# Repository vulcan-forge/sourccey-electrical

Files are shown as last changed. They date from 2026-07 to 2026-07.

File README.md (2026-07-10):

# Sourccey Electrical

Open-source hardware design files for the Sourccey electrical system.

This repository is intended to contain the complete KiCad design source,
component data, and documentation needed to inspect, modify, manufacture,
and assemble the hardware.

## Status

This repository contains the Sourccey v1.3.8 electrical design release.
Always review the release notes and complete your own manufacturing and safety
validation before building hardware.

## Repository layout

The repository is organized by editable design sources, manufacturing outputs,
and supporting documentation:

```text
.
├── pcb/
│   ├── <board-name>.kicad_pro
│   ├── <board-name>.kicad_sch
│   ├── <board-name>.kicad_pcb
│   ├── symbols/             # Project-specific KiCad symbols
│   └── footprints/          # Project-specific KiCad footprints
├── bom/
│   ├── bom.csv              # Human/reviewable bill of materials
│   └── pos.csv              # Pick-and-place / centroid data
├── fab/                     # Released Gerbers and drill files, if tracked
├── docs/                    # Design notes, assembly, and test instructions
└── README.md
```

The generic layout above describes the intended convention for additional
boards. The current checked-in release is organized as follows:

```text
.
|-- pcb/sourccey-v1.3.8/
|   |-- *.kicad_pro       # KiCad project
|   |-- *.kicad_sch       # Main and hierarchical schematics
|   |-- *.kicad_pcb       # PCB layout
|   |-- symbols/           # Project-specific KiCad symbols
|   |-- footprints/        # Project-specific KiCad footprints
|   `-- models/            # Optional 3D model references
|-- manufacturing/sourccey-v1.3.8/
|   |-- gerbers/           # Gerbers, drill files, and Gerber archive
|   |-- bom/               # Bill of materials exports
|   `-- cpl/               # Pick-and-place / component placement exports
|-- docs/                  # Design notes, assembly, and test instructions
`-- README.md
```

Each board should keep its `.kicad_pro`,
`.kicad_sch`, and `.kicad_pcb` files together. Do not commit KiCad lock files,
personal project settings, or backup files.

## Opening the design

The current design is Sourccey v1.3.8 and was saved with KiCad 9.0.

1. Install [KiCad 9](https://www.kicad.org/download/), including the standard
   symbol, footprint, and 3D-model libraries.
2. Clone this repository.
3. Open
   `pcb/sourccey-v1.3.8/sourccey_pcb.kicad_pro`.
4. Review the schematic before opening or editing the PCB.
5. Update the project libraries only with care: project-local symbols and
   footprints should be stored in this repository so the design remains
   reproducible.

The project includes its hierarchical `Power Electronics.kicad_sch` sheet and
the custom DRV8874 symbol and footprint. See the README under the version's
`models/` directory for two optional STEP models that are not yet included.

## BOM and POS data

The `manufacturing/sourccey-v1.3.8/` directory contains the files needed to
order and assemble the board:

- Gerbers for copper, solder mask, solder paste, silkscreen, and the board
  outline, plus the Gerber job file and packaged archive.
- PTH and NPTH drill files for plated and non-plated holes.
- A KiCad BOM export and a vendor-formatted BOM for purchasing.
- KiCad and vendor-formatted CPL (component placement / pick-and-place) data.

These are manufacturing outputs, not the editable source of truth. Regenerate
them from the released KiCad project whenever the design changes.

The BOM should identify at least:

- Reference designators
- Quantity
- Value and footprint
- Manufacturer and manufacturer part number, when known
- Distributor part number, when known
- Designator exclusions or DNP status

The POS file should identify each populated reference, X/Y position, rotation,
side, and the coordinate origin used for the export. BOM and POS exports are
manufacturing inputs: regenerate them from the released KiCad sources and
record the KiCad version and export settings in the release notes.

## Manufacturing components

Manufacturing outputs are generated from the released PCB source. A release
should include, or link to, the corresponding Gerber, drill, drawing, BOM, and
POS package. Keep generated outputs in `fab/` or a release artifact rather than
mixing them with editable KiCad source files.

The checked-in v1.3.8 outputs are under
`manufacturing/sourccey-v1.3.8/`, including original and vendor-formatted BOM
and CPL files, Gerbers, drill files, and the Gerber archive.

The PCB uses 2 oz copper on the copper layers. Confirm the fabricator's stackup
and copper-weight capabilities before ordering.

Before manufacturing, check at minimum:

- Schematic and PCB annotations are synchronized.
- Electrical rules and design rules pass.
- Board outline, mounting holes, clearances, and layer stack are correct.
- Footprints and 3D/component orientations are correct.
- BOM substitutions, DNP parts, polarity, and assembly side are reviewed.
- Gerbers and drill files are inspected in a separate viewer.

## Documentation

See the [Vulcan Robotics documentation](https://vulcanrobotics.ai/docs) for the
broader Sourccey project. This repository is the electrical reference for
wiring and board-level build details. The documentation site also links to the
related hardware, software, and LeRobot-compatible repositories. Software setup
and hardware-kit assembly instructions are currently listed there as coming
soon.

## Release notes

See [RELEASE_NOTES.md](RELEASE_NOTES.md) for the v1.3.8 release summary,
manufacturing package details, and validation record.

## Contributing

Please open an issue before making a substantial design change. Pull requests
should explain the motivation, identify affected boards, and include updated
schematic/PCB files and regenerated BOM/POS or manufacturing outputs when
applicable. Include screenshots or test results for changes that affect layout,
assembly, or electrical behavior.

## Licensing

Unless stated otherwise in a subdirectory, this project is released under the
[CERN Open Hardware Licence Version 2 - Strongly Reciprocal
(CERN-OHL-S-2.0)](https://gitlab.com/ohwr/project/cernohl/-/wikis/uploads/819d71bea3458f71fba6cf4fb0f2de6b/cern_ohl_s_v2.txt).
This license permits personal, educational, commercial, and manufacturing use.
If you distribute a modified design or a product based on it, you must preserve
the notices, make the corresponding source available, and license the modified
covered source under CERN-OHL-S-2.0. Private modifications do not need to be
published unless they are distributed.

Add the full license text as `LICENSE` before publishing the repository.

Third-party symbols, footprints, models, and datasheets may have separate
licenses. Preserve their notices and verify redistribution rights before
committing them.

## Disclaimer

This hardware is provided without warranty. You are responsible for reviewing
the design, complying with applicable laws and safety requirements, and
validating any manufactured or modified hardware before use.

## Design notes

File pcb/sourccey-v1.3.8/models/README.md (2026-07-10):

# Project-local 3D models

The PCB references the following project-local STEP models:

- `DRV8874PWPR.stp`
- `XT30AW-M.stp`

These files were referenced from another developer's local KiCad installation
but were not available in the source tree when this release was assembled.
Place redistributable copies at the paths above to restore those models in
KiCad's 3D viewer. Their absence does not prevent the schematic or PCB editor
from opening.

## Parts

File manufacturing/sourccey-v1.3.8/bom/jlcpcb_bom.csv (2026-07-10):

Comment | Designator | Footprint | JLCPCB Part #
DRV8874PWPR | U2,U3,U1,U5,U4 | PWP0016J_L | C1855818
TPS7A1633DGNR | U9 | MSOP-8-1EP_3x3mm_P0.65mm_EP1.5x1.8mm | C181239
R 249k Ohm | R42 | R_0805_2012Metric | C218450
0.1uF | C32,C5,C43,C40,C56,C57,C19,C23,C54,C55,C10,C7,C20,C3,C37,C6,C22,C52,C17,C18,C35,C8,C46,C9,C30,C21,C15,C49,C16 | C_0603_1608Metric | C14663
22nF | C27,C28,C25,C24,C26 | C_0402_1005Metric | C1532
R 100k Ohm | R3,R1,R8,R6,R45,R31,R9,R40,R7,R2,R4,R5,R10 | R_0805_2012Metric | C25611
D_Schottky | D2 | D_SMB | C22452
R 24k Ohm | R39 | R_0805_2012Metric | C17575
R 100 Ohm | R47 | R_0805_2012Metric | C22775
Conn_01x02_Pin | J9,J13,J18,J16,J5,J6,J4,J14,J11,J8,J2,J17,J15,J12,J3 | AMASS_XT30UPB-M_1x02_P5.0mm_Vertical | C428721
R 10k Ohm | R48,R37,R23,R11,R15,R26,R18,R49,R22,R19,R35,R50,R34,R27,R30,R14,R46 | R_0805_2012Metric | C17414
R 20k Ohm | R13,R25,R21,R17,R29 | R_0805_2012Metric | C4328
22uF | C38,C48,C34,C51 | C_1206_3216Metric | C12891
100uF | C4,C13,C14,C12,C11,C1 | CP_Elec_6.3x7.7 | C3338
R 680 Ohm | R12,R20,R16,R24,R28 | R_0805_2012Metric | C17798
R 1k Ohm | R33 | R_0805_2012Metric | C702831
10uF | C29,C45,C53 | C_0805_2012Metric | C15850
Conn_01x04_Pin | J19 | JST_SH_BM04B-SRSS-TB_1x04-1MP_P1.00mm_Vertical | C160390
Conn_02x20_Odd_Even | J1 | PinHeader_2x20_P2.54mm_Vertical | C5224014
Conn_01x03 | J7 | JST_XH_B3B-XH-A_1x03_P2.50mm_Vertical | C146133
R 12.5m Ohm | R36 | R_2512_6332Metric | C5375465
TestPoint | TP2,TP3,TP6,TP1,TP4,TP5 | TestPoint_Pad_2.0x2.0mm
IRLZ44N | Q3 | TO-220-3_Vertical | C22367197
4700uF | C33,C36,C47,C50 | CP_Radial_D13.0mm_P5.00mm | C29884
10 nF | C41 | C_0603_1608Metric | C57112
R 68 Ohm | R41,R44 | R_0603_1608Metric | C23228
LTC4365DDB | U8 | DFN-8-1EP_2x3mm_P0.5mm_EP0.61x2.2mm | C117337
SW_SPST | FuelGaugeSwitch1,LightSwitch1 | SW_SPDT_PCM12 | C431540
10k NTC | TH1 | JST_XH_B2B-XH-A_1x02_P2.50mm_Vertical | C158012
NMOS | Q1,Q2 | TO-220-3_Vertical | C841350
1uF | C42,C31,C2,C39 | C_0805_2012Metric | C15849
MCP3008 | U7 | SOIC-16_3.9x9.9mm_P1.27mm | C2651321
TCA9517D | U10 | SOIC-8_3.9x4.9mm_P1.27mm | C182421
BQ34Z100PWR-R2 | U6 | TSSOP-14_4.4x5mm_P0.65mm | C7220642
1000uF | C44 | CP_Radial_D10.0mm_P5.00mm | C439782
16V_TVS | D1 | D_SMB | C113990
Conn_01x04_Pin | J20 | Molex_KK-254_AE-6410-04A_1x04_P2.54mm_Vertical | C504991
R 16.5k Ohm | R43 | R_0805_2012Metric | C2930171
R 510k Ohm | R38 | R_0805_2012Metric | C17733
Conn_01x01_Pin | J10 | PinHeader_1x01_P2.54mm_Vertical | C492400

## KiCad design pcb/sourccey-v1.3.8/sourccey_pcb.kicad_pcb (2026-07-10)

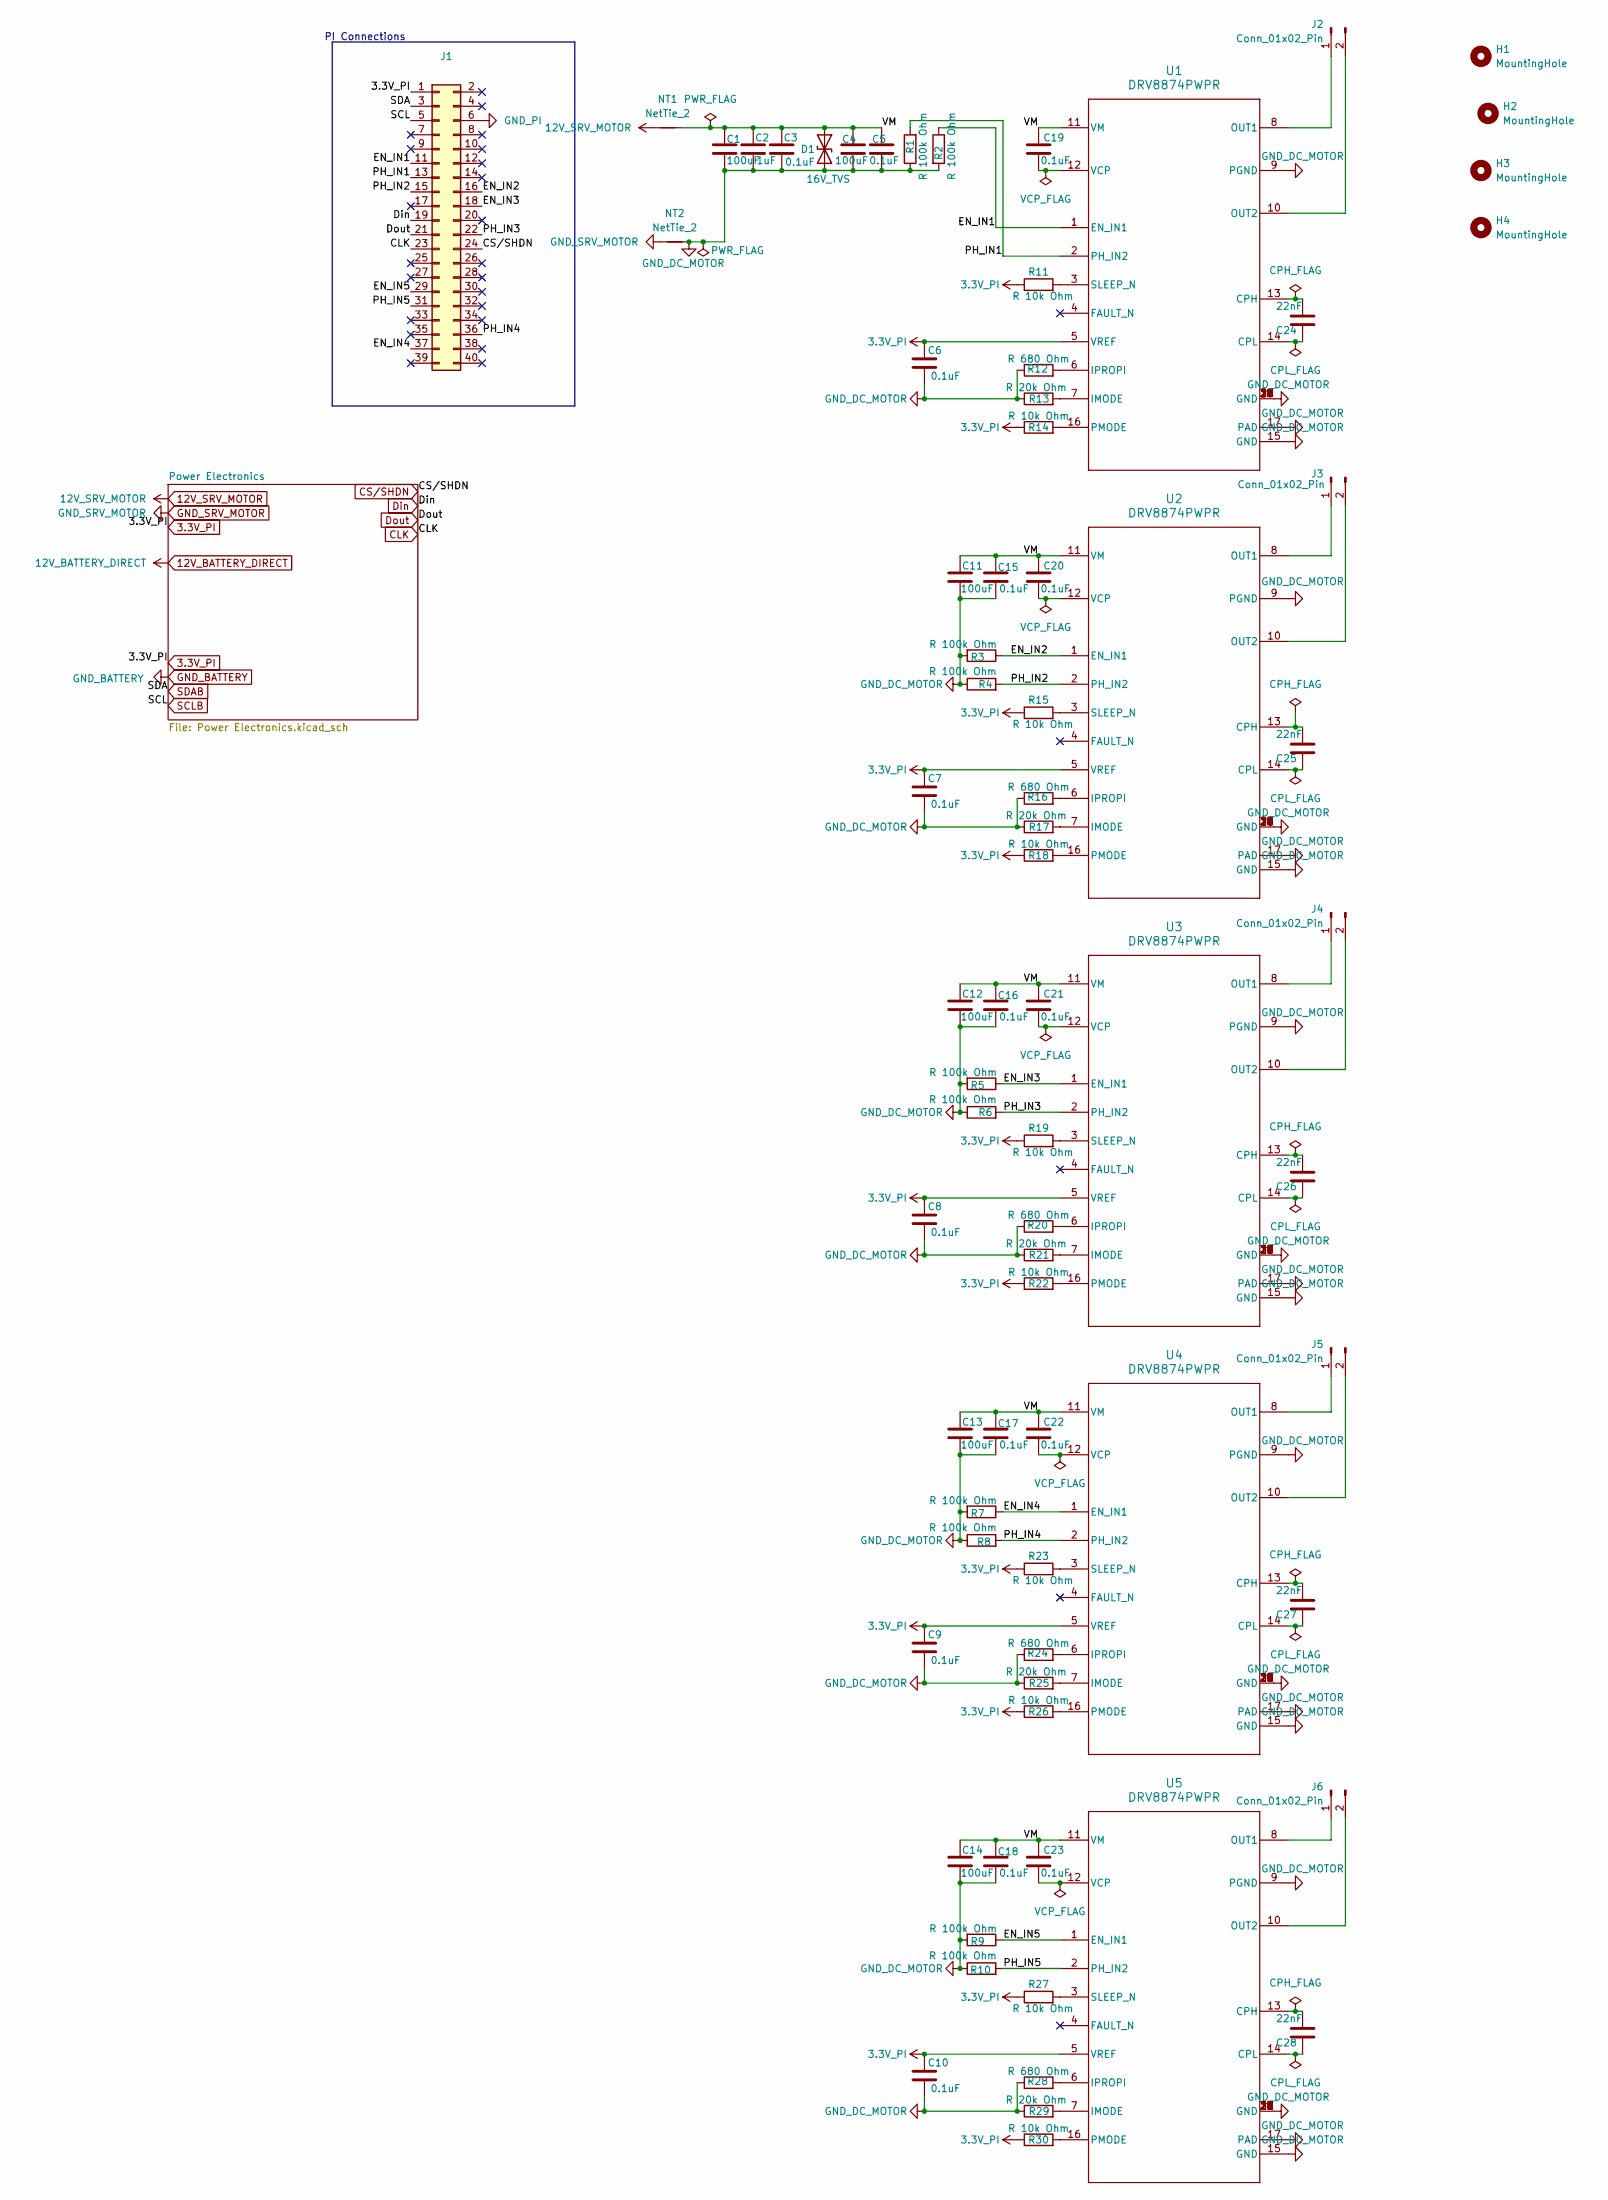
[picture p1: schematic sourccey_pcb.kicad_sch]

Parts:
C1, C4, C11, C12, C13, C14: 100uF; CP_Elec_6.3x7.7
C2: 1uF; C_0805_2012Metric
C3, C5, C6, C7, C8, C9, C10, C15, C16, C17, C18, C19, C20, C21, C22, C23: 0.1uF; C_0603_1608Metric
C24, C25, C26, C27, C28: 22nF; C_0402_1005Metric
D1: 16V_TVS; D_SMB
H1, H2, H3, H4: MountingHole; MountingHole_3.2mm_M3
J1: Conn_02x20_Odd_Even; PinHeader_2x20_P2.54mm_Vertical
J2, J3, J4, J5, J6: Conn_01x02_Pin; AMASS_XT30UPB-M_1x02_P5.0mm_Vertical
NT1, NT2: NetTie_2; NetTie-2_SMD_Pad2.0mm
R1, R2, R3, R4, R5, R6, R7, R8, R9, R10: R 100k Ohm; R_0805_2012Metric
R11, R14, R15, R18, R19, R22, R23, R26, R27, R30: R 10k Ohm; R_0805_2012Metric
R12, R16, R20, R24, R28: R 680 Ohm; R_0805_2012Metric
R13, R17, R21, R25, R29: R 20k Ohm; R_0805_2012Metric
U1, U2, U3, U4, U5: DRV8874PWPR; PWP0016J_L

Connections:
3.3V_PI: C6.2, C7.2, C8.2, C9.2, C10.2, J1.1, R11.1, R14.1, R15.1, R18.1, R19.1, R22.1, R23.1, R26.1, R27.1, R30.1, U1.5 (VREF), U2.5 (VREF), U3.5 (VREF), U4.5 (VREF), U5.5 (VREF); also elsewhere on the board
12V_SRV_MOTOR: NT1.1; also elsewhere on the board
/EN_IN1: J1.11, R2.1, U1.1 (EN_IN1)
/EN_IN2: J1.16, R3.1, U2.1 (EN_IN1)
/EN_IN3: J1.18, R5.1, U3.1 (EN_IN1)
/EN_IN4: J1.37, R7.1, U4.1 (EN_IN1)
/EN_IN5: J1.29, R9.1, U5.1 (EN_IN1)
/PH_IN1: J1.13, R1.2, U1.2 (PH_IN2)
/PH_IN2: J1.15, R4.2, U2.2 (PH_IN2)
/PH_IN3: J1.22, R6.2, U3.2 (PH_IN2)
/PH_IN4: J1.36, R8.2, U4.2 (PH_IN2)
/PH_IN5: J1.31, R10.2, U5.2 (PH_IN2)
/VM: C1.1, C2.1, C3.1, C4.1, C5.1, C11.1, C12.1, C13.1, C14.1, C15.1, C16.1, C17.1, C18.1, C19.1, C20.1, C21.1, C22.1, C23.1, D1.1 (A1), NT1.2, U1.11 (VM), U2.11 (VM), U3.11 (VM), U4.11 (VM), U5.11 (VM)
CLK: J1.23; also elsewhere on the board
CS/SHDN: J1.24; also elsewhere on the board
Din: J1.19; also elsewhere on the board
Dout: J1.21; also elsewhere on the board
GND_DC_MOTOR: C1.2, C2.2, C3.2, C4.2, C5.2, C6.1, C7.1, C8.1, C9.1, C10.1, C11.2, C12.2, C13.2, C14.2, C15.2, C16.2, C17.2, C18.2, D1.2 (A2), NT2.2, R1.1, R2.2, R3.2, R4.1, R5.2, R6.1, R7.2, R8.1, R9.2, R10.1, R12.1, R13.1, R16.1, R17.1, R20.1, R21.1, R24.1, R25.1, R28.1, R29.1, U1.9 (PGND), U1.15 (GND), U1.17 (PAD), U1.18 (GND), U1.19 (GND), U1.20 (GND), U1.21 (GND), U1.22 (GND), U1.23 (GND), U1.24 (GND), U1.25 (GND), U1.26 (GND), U1.27 (GND), U1.28 (GND), U1.29 (GND), U1.30 (GND), U1.31 (GND), U1.32 (GND), U2.9 (PGND), U2.15 (GND), U2.17 (PAD), U2.18 (GND), U2.19 (GND), U2.20 (GND), U2.21 (GND), U2.22 (GND), U2.23 (GND), U2.24 (GND), U2.25 (GND), U2.26 (GND), U2.27 (GND), U2.28 (GND), U2.29 (GND), U2.30 (GND), U2.31 (GND), U2.32 (GND), U3.9 (PGND), U3.15 (GND), U3.17 (PAD), U3.18 (GND), U3.19 (GND), U3.20 (GND), U3.21 (GND), U3.22 (GND), U3.23 (GND), U3.24 (GND), U3.25 (GND), U3.26 (GND), U3.27 (GND), U3.28 (GND), U3.29 (GND), U3.30 (GND), U3.31 (GND), U3.32 (GND), U4.9 (PGND), U4.15 (GND), U4.17 (PAD), U4.18 (GND), U4.19 (GND), U4.20 (GND), U4.21 (GND), U4.22 (GND), U4.23 (GND), U4.24 (GND), U4.25 (GND), U4.26 (GND), U4.27 (GND), U4.28 (GND), U4.29 (GND), U4.30 (GND), U4.31 (GND), U4.32 (GND), U5.9 (PGND), U5.15 (GND), U5.17 (PAD), U5.18 (GND), U5.19 (GND), U5.20 (GND), U5.21 (GND), U5.22 (GND), U5.23 (GND), U5.24 (GND), U5.25 (GND), U5.26 (GND), U5.27 (GND), U5.28 (GND), U5.29 (GND), U5.30 (GND), U5.31 (GND), U5.32 (GND); also elsewhere on the board
GND_PI: J1.6; also elsewhere on the board
GND_SRV_MOTOR: NT2.1; also elsewhere on the board
unnamed: J2.1, U1.8 (OUT1)
unnamed: J2.2, U1.10 (OUT2)
unnamed: J3.1, U2.8 (OUT1)
unnamed: J3.2, U2.10 (OUT2)
unnamed: J4.1, U3.8 (OUT1)
unnamed: J4.2, U3.10 (OUT2)
unnamed: J5.1, U4.8 (OUT1)
unnamed: J5.2, U4.10 (OUT2)
unnamed: J6.1, U5.8 (OUT1)
unnamed: J6.2, U5.10 (OUT2)
unnamed: C24.1, U1.13 (CPH)
unnamed: C24.2, U1.14 (CPL)
unnamed: R13.2, U1.7 (IMODE)
unnamed: R12.2, U1.6 (IPROPI)
unnamed: R14.2, U1.16 (PMODE)
unnamed: R11.2, U1.3 (SLEEP_N)
unnamed: C19.2, U1.12 (VCP)
unnamed: C25.1, U2.13 (CPH)
unnamed: C25.2, U2.14 (CPL)
unnamed: R17.2, U2.7 (IMODE)
unnamed: R16.2, U2.6 (IPROPI)
unnamed: R18.2, U2.16 (PMODE)
unnamed: R15.2, U2.3 (SLEEP_N)
unnamed: C20.2, U2.12 (VCP)
unnamed: C26.1, U3.13 (CPH)
unnamed: C26.2, U3.14 (CPL)
unnamed: R21.2, U3.7 (IMODE)
unnamed: R20.2, U3.6 (IPROPI)
unnamed: R22.2, U3.16 (PMODE)
unnamed: R19.2, U3.3 (SLEEP_N)
unnamed: C21.2, U3.12 (VCP)
unnamed: C27.1, U4.13 (CPH)
unnamed: C27.2, U4.14 (CPL)
unnamed: R25.2, U4.7 (IMODE)
unnamed: R24.2, U4.6 (IPROPI)
unnamed: R26.2, U4.16 (PMODE)
unnamed: R23.2, U4.3 (SLEEP_N)
unnamed: C22.2, U4.12 (VCP)
unnamed: C28.1, U5.13 (CPH)
unnamed: C28.2, U5.14 (CPL)
unnamed: R29.2, U5.7 (IMODE)
unnamed: R28.2, U5.6 (IPROPI)
unnamed: R30.2, U5.16 (PMODE)
unnamed: R27.2, U5.3 (SLEEP_N)
unnamed: C23.2, U5.12 (VCP)
SCLB: J1.5; also elsewhere on the board
SDAB: J1.3; also elsewhere on the board

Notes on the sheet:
PI Connections

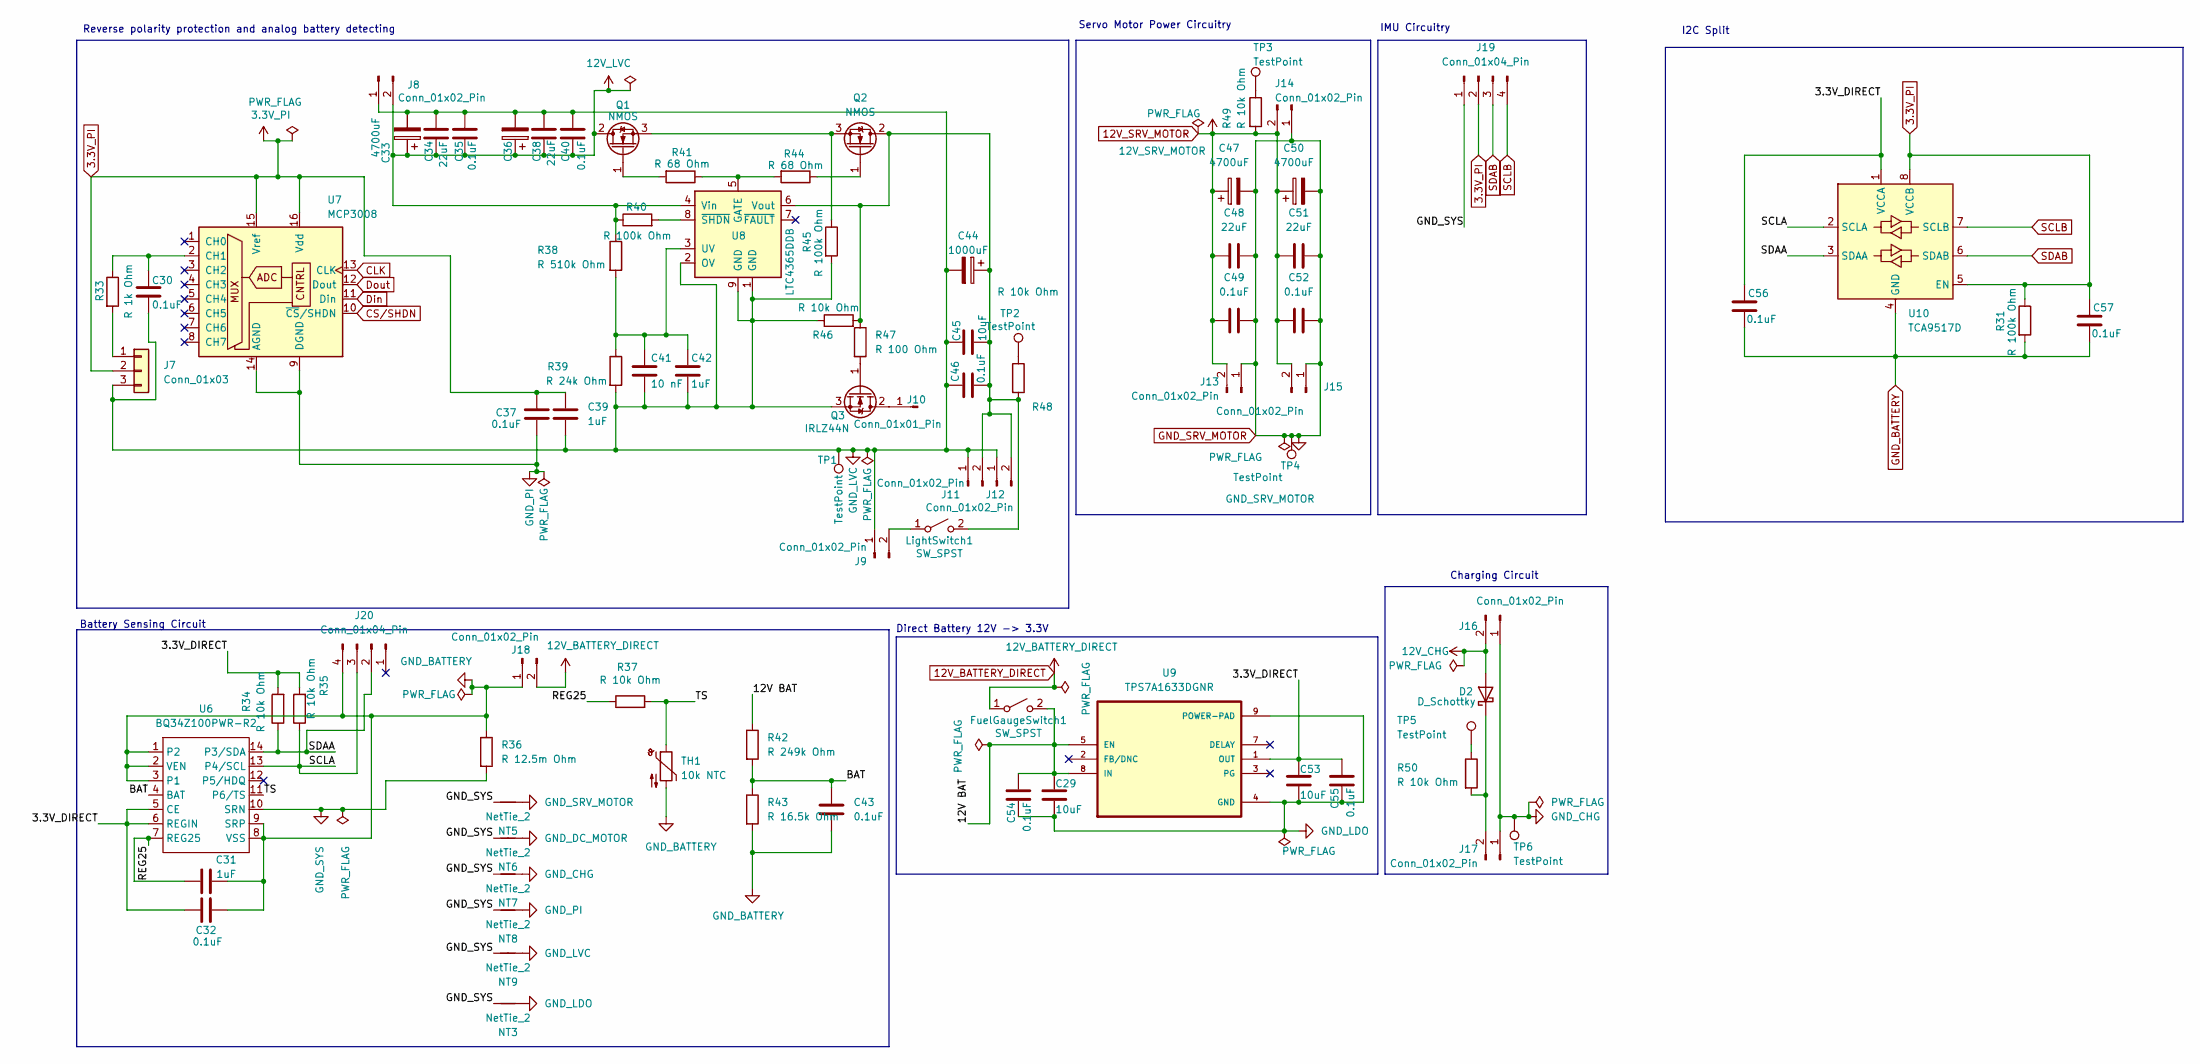
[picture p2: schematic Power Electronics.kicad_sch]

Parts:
C29, C45, C53: 10uF; C_0805_2012Metric
C30, C32, C35, C37, C40, C43, C46, C49, C52, C54, C55, C56, C57: 0.1uF; C_0603_1608Metric
C31, C39, C42: 1uF; C_0805_2012Metric
C33, C36, C47, C50: 4700uF; CP_Radial_D13.0mm_P5.00mm
C34, C38, C48, C51: 22uF; C_1206_3216Metric
C41: 10 nF; C_0603_1608Metric
C44: 1000uF; CP_Radial_D10.0mm_P5.00mm
D2: D_Schottky; D_SMB
FuelGaugeSwitch1: SW_SPST; SW_SPDT_PCM12
J7: Conn_01x03; JST_XH_B3B-XH-A_1x03_P2.50mm_Vertical
J8, J9, J11, J12, J13, J14, J15, J16, J17, J18: Conn_01x02_Pin; AMASS_XT30UPB-M_1x02_P5.0mm_Vertical
J10: Conn_01x01_Pin; PinHeader_1x01_P2.54mm_Vertical
J19: Conn_01x04_Pin; JST_SH_BM04B-SRSS-TB_1x04-1MP_P1.00mm_Vertical
J20: Conn_01x04_Pin; Molex_KK-254_AE-6410-04A_1x04_P2.54mm_Vertical
LightSwitch1: SW_SPST; SW_SPDT_PCM12
NT3, NT5, NT6, NT7, NT8, NT9: NetTie_2; NetTie-2_SMD_Pad2.0mm
Q1, Q2: NMOS; TO-220-3_Vertical
Q3: IRLZ44N; TO-220-3_Vertical
R31, R40, R45: R 100k Ohm; R_0805_2012Metric
R33: R 1k Ohm; R_0805_2012Metric
R34, R35, R37, R46, R48, R49, R50: R 10k Ohm; R_0805_2012Metric
R36: R 12.5m Ohm; R_2512_6332Metric
R38: R 510k Ohm; R_0805_2012Metric
R39: R 24k Ohm; R_0805_2012Metric
R41, R44: R 68 Ohm; R_0603_1608Metric
R42: R 249k Ohm; R_0805_2012Metric
R43: R 16.5k Ohm; R_0805_2012Metric
R47: R 100 Ohm; R_0805_2012Metric
TH1: 10k NTC; JST_XH_B2B-XH-A_1x02_P2.50mm_Vertical
TP1, TP2, TP3, TP4, TP5, TP6: TestPoint; TestPoint_Pad_2.0x2.0mm
U6: BQ34Z100PWR-R2; TSSOP-14_4.4x5mm_P0.65mm
U7: MCP3008; SOIC-16_3.9x9.9mm_P1.27mm
U8: LTC4365DDB; DFN-8-1EP_2x3mm_P0.5mm_EP0.61x2.2mm
U9: TPS7A1633DGNR; MSOP-8-1EP_3x3mm_P0.65mm_EP1.5x1.8mm
U10: TCA9517D; SOIC-8_3.9x4.9mm_P1.27mm

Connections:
3.3V_PI: C37.2, C39.1, C57.2, J7.2, J19.2, R31.1, U7.15 (Vref), U7.16 (Vdd), U10.5 (EN), U10.8 (VCCB); also elsewhere on the board
12V_BATTERY_DIRECT: FuelGaugeSwitch1.1 (A), J18.2
12V_CHG: D2.2 (A), J16.2
12V_LVC: C33.1, C34.2, C35.1, C36.1, C38.1, C40.1, J8.2, Q1.2 (D), R38.1, R40.1, U8.4 (Vin)
12V_SRV_MOTOR: C47.1, C48.2, C49.1, C50.1, C51.2, C52.2, J13.2, J14.2, J15.2, R49.2; also elsewhere on the board
/Power Electronics/3.3V_DIRECT: C32.1, C53.1, C55.2, C56.2, R34.2, R35.2, U6.5 (CE), U6.6 (REGIN), U9.1 (OUT), U10.1 (VCCA)
/Power Electronics/12V BAT: C29.1, C54.2, FuelGaugeSwitch1.2 (B), R42.1, U9.5 (EN), U9.8 (IN)
/Power Electronics/BAT: C43.1, R42.2, R43.1, U6.4 (BAT)
/Power Electronics/REG25: C31.1, R37.1, U6.7 (REG25)
/Power Electronics/SCLA: J20.3, R35.1, U6.13 (P4/SCL), U10.2 (SCLA)
/Power Electronics/SDAA: J20.2, R34.1, U6.14 (P3/SDA), U10.3 (SDAA)
/Power Electronics/TS: R37.2, TH1.1, U6.11 (P6/TS)
CLK: U7.13 (CLK); also elsewhere on the board
CS/SHDN: U7.10 (~CS/SHDN); also elsewhere on the board
Din: U7.11 (Din); also elsewhere on the board
Dout: U7.12 (Dout); also elsewhere on the board
GND_BATTERY: C31.2, C32.2, C43.2, C56.1, C57.1, J18.1, J20.4, R31.2, R36.1, R43.2, TH1.2, U6.1 (P2), U6.2 (VEN), U6.3 (P1), U6.8 (VSS), U6.9 (SRP), U10.4 (GND)
GND_CHG: J16.1, J17.1, NT7.1, TP6.1
GND_DC_MOTOR: NT6.1; also elsewhere on the board
GND_LDO: C29.2, C53.2, C54.1, C55.1, NT3.1, U9.4 (GND), U9.9 (POWER-PAD)
GND_LVC: C30.1, C33.2, C34.1, C35.2, C36.2, C38.2, C39.2, C40.2, C41.1, C42.2, C44.2, C45.1, C46.2, J7.3, J8.1, J9.1, J11.1, J12.1, NT9.1, Q3.3 (S), R39.2, R45.2, R46.1, TP1.1, U8.1 (GND), U8.2 (OV), U8.9 (GND)
GND_PI: C37.1, NT8.1, U7.9 (DGND), U7.14 (AGND); also elsewhere on the board
GND_SRV_MOTOR: C47.2, C48.1, C49.2, C50.2, C51.1, C52.1, J13.1, J14.1, J15.1, NT5.1, TP4.1; also elsewhere on the board
GND_SYS: J19.1, NT3.2, NT5.2, NT6.2, NT7.2, NT8.2, NT9.2, R36.2, U6.10 (SRN)
unnamed: D2.1 (K), J17.2, R50.2
unnamed: J7.1, R33.2
unnamed: J9.2, LightSwitch1.1 (A)
unnamed: J10.1, Q3.2 (D)
unnamed: C44.1, C45.2, C46.1, J11.2, J12.2, LightSwitch1.2 (B), Q2.2 (D), R46.2, R47.1, R48.2, U8.6 (Vout)
unnamed: Q1.1 (G), R41.2
unnamed: Q1.3 (S), Q2.3 (S), R45.1
unnamed: Q2.1 (G), R44.1
unnamed: Q3.1 (G), R47.2
unnamed: R48.1, TP2.1
unnamed: R49.1, TP3.1
unnamed: R50.1, TP5.1
unnamed: C30.2, R33.1, U7.2 (CH1)
unnamed: R41.1, R44.2, U8.5 (GATE)
unnamed: C41.2, C42.1, R38.2, R39.1, U8.3 (UV)
unnamed: R40.2, U8.8 (~SHDN)
SCLB: J19.4, U10.7 (SCLB); also elsewhere on the board
SDAB: J19.3, U10.6 (SDAB); also elsewhere on the board

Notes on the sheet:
Reverse polarity protection and analog battery detecting
I2C Split
Servo Motor Power Circuitry
IMU Circuitry
Battery Sensing Circuit
Charging Circuit
Direct Battery 12V -> 3.3V

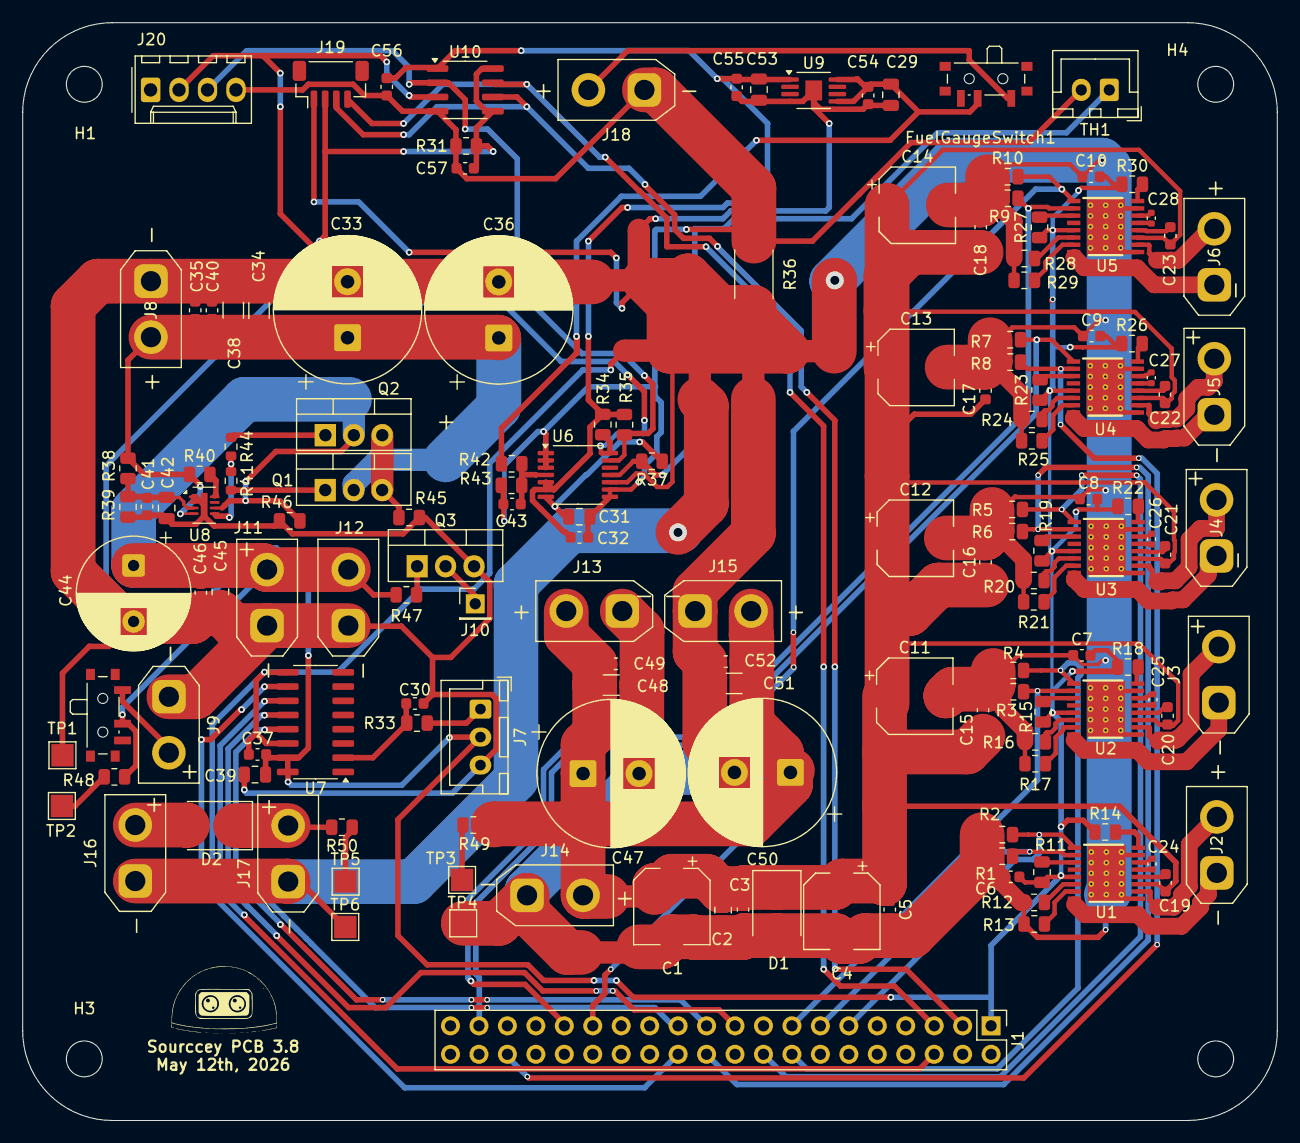
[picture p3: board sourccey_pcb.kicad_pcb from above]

Board: 2 copper layers, 112.0 x 98.0 mm, 162 parts (0 on the bottom side), 98 nets.

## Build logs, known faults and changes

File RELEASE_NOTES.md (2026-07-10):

# Sourccey Electrical v1.3.8

## Release summary

This release contains the Sourccey v1.3.8 electrical design files and the
corresponding manufacturing package.

## Design sources

- KiCad version: 9.0
- Project: `pcb/sourccey-v1.3.8/`
- Main project: `sourccey_pcb.kicad_pro`
- Copper: 2 oz copper on the copper layers
- Includes the main schematic, hierarchical `Power Electronics.kicad_sch`
  sheet, custom DRV8874 symbol, and custom DRV8874 footprint.

## Manufacturing package

The manufacturing outputs are in `manufacturing/sourccey-v1.3.8/` and include:

- Gerber copper, solder mask, solder paste, silkscreen, and outline files
- PTH and NPTH drill files
- Gerber job file and packaged Gerber archive
- KiCad and vendor-formatted BOM files
- KiCad and vendor-formatted CPL / pick-and-place files

The BOM and placement exports should be regenerated from the released KiCad
source whenever the design changes.

## Validation

The maintainer has completed the pre-release validation checklist documented in
the README, including electrical/design-rule review, board geometry and
mounting review, component orientation review, BOM and assembly review, and
independent Gerber and drill-file inspection.

## Known limitations

- Optional STEP models referenced by the project are not included.
- Software setup and hardware-kit assembly documentation are maintained on
  the [Vulcan Robotics documentation site](https://vulcanrobotics.ai/docs) and
  may be completed separately.
